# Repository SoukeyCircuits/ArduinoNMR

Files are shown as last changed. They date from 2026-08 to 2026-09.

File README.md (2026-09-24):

August 2026 Update and Explainer:

IMPORTANT DISCLAIMER: The repository here is only the spectrometer for an NMR. You will need to purchase a sufficiently homogeneous magnet and a power amplifier to acquire any kind of measurement. A power amplifier can be purchased from aliexpress for under $100 but your quality and safety will vary significantly. If you are looking for a magnet, there are a few open source options that you can build yourself or commercially available ones.

The magnet used for demonstration can be found here: 
https://www.spincore.com/products/Magnets/
I will do a build of this one: 
https://www.hardware-x.com/article/S2468-0672(25)00029-X/fulltext 
I'm unsure if this is of high quality but would be an interesting build:
https://science.slc.edu/mfrey/project/3dprintnmrmandhalas_update2/

To do list: 
	
  -Upload Accessory PCB files
	
  -Add alternative attenuator and LNA (10 MHz minimum frequency but lower price).
	
  -Upload control code
	
  -Upload Arduino NMR pulse code (being edited for release)
	
  -Upload CAD/CAM designs for the housing and end plates
	
  -Add Arduino Giga Display + display software
	
  -Show preliminary results from working device
	
  -Add non JLC BOM (Mouser, Aliexpress, etc)
	
  -Add raspberry pi multiple instrument control software.

  -Fix phase error discovered at OpenSauce 2026.
  
  -Implement digital filtering techniques.
  
The main sections of the Arduino NMR are the RF synthesis, RF input, and the Tayloe detector. 

RF synthesis begins with the SI5351A-B-GM chip connected to an ABM8G-25.000MHZ-4Y-T3, a  25 MHz crystal oscillator. The 20QFN package for the SI5351 was specifically chosen over the 16QFN as it was having issues with the Etherkit SI5351 library and not indexing the clock outputs correctly. The SI5351A-B-GM is still unable to use CLK6 and CLK7 as they are handled differently from CLK0-CLK5. Although it would be possible to control all 8 outputs, the function is sufficient for the design as is. The primary output clocks CLK0-CLK3 are connected to an ADG904BRUZ in an SP4T configuration. The switch allows for indexing either 0°, 90°, 180°, and 270° phase for a single frequency or 0° and a second phase at two separate frequencies. The lowest frequency for a 0°-90° control is 4.76 MHz due to the lower PLL limit of 600 MHz and the upper divider limit of int-127. For 0°-90°-180°, the lower limit is twice that at 9.52 MHz. Finally, for full 0°-90°-180°-270° control, the lower limit is 14.17 MHz.

The output is then fed into a PE4251MLI-Z SPDT switch. Since both single and dual frequency setups have an available channel containing the 0° at the Larmor frequency, when not transmitting, the channel can be used for Homodyne demodulation. Alternatively, one of the clocks can be set to a secondary offset frequency for Heterodyne demodulation. 

When actively transmitting, the output is sent through a PE43650 attenuator for digital control of the RF power output. Although the PE43650 was chosen based on availability and price, it would be advantageous to include the PE43711B-Z as an option in the future. The PE43650 has 0.5 dB step sizes with a maximum attenuation of 15.5 dB, but an improvement with the PE43711B-Z would give 0.25 dB step sizes and a maximum attenuation of 31.5 dB. For these applications, 0.5 dB is sufficient and maximum power can be limited by an external attenuator on the output(s).

fter attenuation, the final stage is either a bridged solder jumper, or another PE4251MLI-Z SPDT switch. This switch is what controls the two TX output options. Each output will need its own external attenuator to limit the maximum power output as well as a filter. The SI5351 only emits a square shaped output and harmonic frequencies must be filtered out for a pure sinusoidal output at the desired frequency. This allows for connecting a single spectrometer to multiple instruments each with their own dedicated TX and RX ports.

After amplification, further accessory parts are available for filtering, conditioning, and pulse breakthrough limitation. All of these accessories fit inside a 50x25x25mm aluminum enclosure available on Aliexpress but require drilling holes for the SMA connectors. The first accessory is the LC filter. This design is able to fit a 7 pole LC filter within the small enclosure for high off frequency rejection for both ≤100W and ≤5W depending on which side is populated. 

Another accompanying accessory is the crossed-diode duplexer to reject low power noise from the amplifier while passing the high powered pulse. By populating the diodes at the top of the design and not populating the lower diodes, this gives a path of 3 pairs of crossed diodes before reaching the center SMA port leading to the magnet. By changing the diodes populated to the bottom half of the board, bridging the top solder jumper, and not including the center SMA header, the same board can be used for crossed diodes to ground. It should be said, never try to combine these two functions as they are for separate uses and it could damage your equipment.

When attempting to capture the NMR signal, always filter before the signal enters the RX ports. Like with the TX ports, the signal can either go into the default solder bridged SMA connector, or be actively switched between the two RX ports. Once the signal has entered the RX portion of the board, there is one additional PE4251MLI-Z SPDT switch to protect the preamplifier from the pulse breakthrough. This switch is normally closed to a 50 Ω terminator but can be GPIO controlled to open after the desired deadtime. When open, the signal passes into a multiple stage low noise amplifier (LNA). The LNA is a dual stage PHA-13HLN+ amplifier with approximately 48-51 dB of gain with a noise figure ≤3. An additional design with budget conscience in mind alternatively uses a dual GALI-S66+ design for $10 instead of $30. This design has a smaller 42 dB gain and has a similar noise figure above 10 MHz but the noise figure skyrockets below 10 MHz. 

After the preamplifier, the design has one of two options for configuration, bridging the triple solder pad to the left, sends the signal directly into the Tayloe detector. Alternatively, bridging the solder to the right and additionally at the end allows for additional filtering after the LNA. If RX1 and RX2 are close in frequency, the filter can be set to cut off just at the frequency of interest. If the desire is for wide band operation from 1-100 MHz, it is advised to still filter the 100+ MHz frequency as both LNAs have additional noise at or above that frequency. The performance of the LNA and accompanying filtering can be measured by disconnecting C43, not powering the 5V line, and connecting to the center SMA connector as the output. It is advised to validate the gain and noise figure of the LNA prior to connecting to the SN74LV4052ADR. 

Once the signal is amplified and filtered, the signal will pass through the C43 DC blocking capacitor and enter a DC offset of 1.66V using a 3.3V voltage splitter. The signal will then enter the SN74LV4052ADR setup in the configuration of a Tayloe detector inspired by the ESP32 designed https://github.com/thaaraak. As a brief overview, by mixing the 0° and 90° signals from the SI5351 into the SN74LV4052ADR A & B pins and our amplified signal into the COM port, we are able to split the IF into their 0°, 90°, 180°, and 270° components. By then connecting the 0° to the positive end and 180° into the negative end of an operational amplifier, the in-phase signal is the resulting output and can be measured. By repeating with the 90° and 270° components, the quadrature signal can also be acquired. 

Finally, the I/Q signal is measured using the Arduino Giga’s built in ADC pins. Since the clock frequency of the Arduino Giga is 480 MHz, the ADC is capable of measuring up to 12.5 Msps for each channel. This uses the https://github.com/Bexin3/STMSpeeduino as a starting point but uses my built in pulse control software to handle the timing. 

## Repository layout

See `CHANGELOG.md` for what changed since June.

- `BOM_09_23_26.csv` — every part for the main board: JLCPCB assembly, hand solder (front and back), and off-board items with links
- `Arduino_NMR_09_23_26/KiCad_Files/Arduino_NMR_5.4.kicad_pro` — main board; open in KiCad 10
- `Arduino_NMR_09_23_26/KiCad_Files/production/1_jlcpcb_assembly.csv` + `1_jlcpcb_assembly_cpl.csv` — the files to upload to JLCPCB
- `Arduino_NMR_09_23_26/Power-USBC/` — USB-C PD power board (9 V in, +8 V / +3.3 V out)
- `Arduino_NMR_09_23_26/Power_Barrel/` — barrel-jack version of the power board
- `Past Boards/` — earlier revisions, kept as they were

Each power board folder has its own README, BOM, schematic PDF and JLCPCB files. Released boards are tagged in git (e.g. `v5.4-production`).

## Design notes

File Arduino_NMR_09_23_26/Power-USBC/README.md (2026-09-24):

# Power-USBC

USB-C PD power board for the Arduino NMR. It negotiates a fixed 9 V from any USB-C PD supply (HUSB238A-BB001), makes the +8 V (LNA) and +3.3 V rails on board, and feeds them to the main board over J2 (1×12) and J4 (2×5 right-angle).

- **Over-voltage interlock:** a TL431A cuts the input if the supply ever delivers more than ~10 V.
- **Indicators:** LED1–LED3 show +9V_SYS, +8V and +3V3.
- **2 layers, 1.6 mm.**

| File | What |
|---|---|
| `BOM_USBC_09_23_26.csv` | every part: JLCPCB assembly, hand solder, and off-board items |
| `USBC_Power_schematic.pdf` | the schematic |
| `KiCad_Files/usbc-power.kicad_pro` | open this in KiCad 10 |
| `KiCad_Files/production/1_jlcpcb_assembly.csv` + `_cpl.csv` | the files to upload to JLCPCB |

## Known issues

- **The R23 failsafe is in the schematic but not on the PCB.** The schematic has R23 and R32 at 6.04k in parallel, so a single failed resistor gives 12 V (caught by the interlock) instead of 28 V. The PCB and BOM still have a single 3.00k R23. Run *Update PCB from Schematic* before the next order.
- **J10 (USB-C receptacle):** JLC doesn't stock the GCT USB4105-GF-A-120 (48 V). Either hand solder it or switch to the HRO TYPE-C-31-M-12 (C165948), which is rated 20 V only.
- **IC25 (BD33GA5WEFJ-E2)** is out of stock at JLC. Hand solder it.
- **D20 (SMAJ24A)** clamps at 38.9 V, which is above U20's 33 V absolute maximum. Acceptable for a test board.

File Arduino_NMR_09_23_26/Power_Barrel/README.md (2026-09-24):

# Power_Barrel

Barrel-jack version of the Power-USBC board. The PD negotiation and interlock are gone. It takes a DC input on J1 (PJ-058B), makes the +8 V (BD80GC0VEFJ-ME2) and +3.3 V (BD33GA5WEFJ-E2) rails, and feeds the main board over the same J2 (1×12) and J4 (2×5 right-angle) connectors.

| File | What |
|---|---|
| `BOM_Barrel_09_23_26.csv` | every part: JLCPCB assembly, hand solder, and off-board items |
| `Barrel_Power_schematic.pdf` | the schematic |
| `KiCad_Files/Barrel_Power.kicad_pro` | open this in KiCad 10 |
| `KiCad_Files/production/1_jlcpcb_assembly.csv` + `_cpl.csv` | the files to upload to JLCPCB |

## Status

**Not yet built or ordered.** The input voltage range hasn't been confirmed against the regulators; check the BD80 dropout before choosing a supply. IC25 is out of stock at JLC, so hand solder it.

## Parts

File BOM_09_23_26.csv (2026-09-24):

Assembly | Value | Designator | Footprint | Qty | Category | Part Number | Supplier | Link | Notes
JLCPCB assembly (front) | 0603CS-5N1XJLW | L1, L3 | 0603 | 2 | SMD |  | JLCPCB |  | Pick from JLC suggested parts
JLCPCB assembly (front) | 1 nF | C40, C64 | 0402 | 2 | SMD | 0402B102K500NT | JLCPCB
JLCPCB assembly (front) | 1 nF | C2, C4, C5, C6, C15, C16 | 0805 | 6 | SMD |  | JLCPCB |  | Pick from JLC suggested parts
JLCPCB assembly (front) | 1 uF | C48 | 0805 | 1 | SMD |  | JLCPCB |  | Pick from JLC suggested parts
JLCPCB assembly (front) | 1.5 k | R16, R17 | 0402 | 2 | SMD | 0402WGF1501TCE | JLCPCB
JLCPCB assembly (front) | 1.5 pF | C20, C46 | 0402 | 2 | SMD | 0402CG1R5C500NT | JLCPCB
JLCPCB assembly (front) | 10 uF | C41, C65 | 0805 | 2 | SMD | GRM21BR61H106KE43L | JLCPCB
JLCPCB assembly (front) | 100 nF | C1, C3, C14, C34, C43 | 0805 | 5 | SMD |  | JLCPCB |  | Pick from JLC suggested parts
JLCPCB assembly (front) | 100 nF | C31, C61 | 0402 | 2 | SMD | CL05B104KO5NNNC | JLCPCB
JLCPCB assembly (front) | 100 pF | C8, C9, C27, C28 | 0805 | 4 | SMD |  | JLCPCB |  | Pick from JLC suggested parts
JLCPCB assembly (front) | 100Ω | R1, R6, R7, R13, R14, R15 | 0805 | 6 | SMD |  | JLCPCB |  | Pick from JLC suggested parts
JLCPCB assembly (front) | 10kΩ | R3, R4, R9, R10 | 0805 | 4 | SMD |  | JLCPCB |  | Pick from JLC suggested parts
JLCPCB assembly (front) | 1kΩ | R5, R8 | 0805 | 2 | SMD | 0805W8F1001T5E | JLCPCB
JLCPCB assembly (front) | 2.2 uF | C30, C45, C60, C66 | 0603 | 4 | SMD |  | JLCPCB |  | Pick from JLC suggested parts
JLCPCB assembly (front) | 50Ω | R18 | 0805 | 1 | SMD |  | JLCPCB |  | Pick from JLC suggested parts
JLCPCB assembly (front) | ABM8G-25.000MHZ-B4Y-T | Y1 | Crystal_SMD_SeikoEpson_FA238-4Pin_3.2x2.5mm_HandSoldering | 1 | SMD |  | JLCPCB |  | Pick from JLC suggested parts
JLCPCB assembly (front) | ADG904BRUZ-REEL7 | IC3 | ADG904BRUZ | 1 | SMD |  | JLCPCB |  | Pick from JLC suggested parts
JLCPCB assembly (front) | LM4562MAX/NOPB | U4 | SOIC-8-1EP_3.9x4.9mm_P1.27mm_EP2.29x3mm_nobottomgnd | 1 | SMD |  | JLCPCB |  | Pick from JLC suggested parts
JLCPCB assembly (front) | LQH32DZ150K53L | L2, L15 | 1210 | 2 | SMD |  | JLCPCB |  | Pick from JLC suggested parts
JLCPCB assembly (front) | PE4251MLI-Z | IC4, IC8, IC10, IC11 | SOP65P490X106-9N | 4 | SMD |  | JLCPCB |  | Pick from JLC suggested parts
JLCPCB assembly (front) | PE43711B-Z | AT2 | PE43711B-Z | 1 | SMD |  | JLCPCB |  | Pick from JLC suggested parts
JLCPCB assembly (front) | PHA-13HLN+ | IC13, IC14 | PHA13HLN | 2 | SMD |  | JLCPCB |  | Pick from JLC suggested parts
JLCPCB assembly (front) | SN74LV1T04DBVR | IC1, IC2, IC12 | SOT95P280X145-5N | 3 | SMD |  | JLCPCB |  | Pick from JLC suggested parts
JLCPCB assembly (front) | SN74LV4052ADR | U1 | SOIC-16_3.9x9.9mm_P1.27mm | 1 | SMD |  | JLCPCB |  | Pick from JLC suggested parts
JLCPCB assembly (front) | Si5351A-B-GM | U2 | QFN-20-1EP_4x4mm_P0.5mm_EP2.7x2.7mm | 1 | SMD |  | JLCPCB |  | Pick from JLC suggested parts
JLCPCB assembly (front) | TLV74125PDBVR | IC5 | SOT95P280X145-5N | 1 | SMD |  | JLCPCB |  | Pick from JLC suggested parts
Hand solder (back) | 100 uF | C47 | C_Radial_D5.0mm_H5.0mm_P2.00mm | 1 | Bulk cap (THT) |  |  |  | Through-hole electrolytic on the BACK side - hand solder.
Hand solder (back) | Conn_01x02 | J4, J10, J12 | PinHeader_1x02_P2.54mm_Vertical | 3 | Connector (THT) |  |  |  | Through-hole connector on the BACK side - hand solder.
Hand solder (back) | Digital | J5 | PinHeader_2x18_P2.54mm_Vertical | 1 | Connector (THT) |  |  |  | Through-hole connector on the BACK side - hand solder.
Hand solder (back) | 100 nF | C10, C17, C18, C19, C24 | 0805 | 5 | Decoupling |  |  |  | Back-side hand soldering.
Hand solder (back) | 100 pF | C29, C33, C39 | 0805 | 3 | Decoupling |  |  |  | Back-side hand soldering.
Hand solder (front) | Conn_01x05 | J7 | PinHeader_1x05_P2.54mm_Vertical | 1 | Connector (THT) |  |  |  | Through-hole connector - hand solder.
Hand solder (front) | Conn_01x12 | J2 | PinHeader_1x12_P2.54mm_Vertical | 1 | Connector (THT) |  |  |  | Through-hole connector - hand solder.
Hand solder (front) | RX1 | J11 | SMA_Amphenol_901-144_Vertical | 1 | Connector (THT) |  |  |  | Through-hole connector - hand solder.
Hand solder (front) | RX2 | J40 | SMA_Amphenol_901-144_Vertical | 1 | Connector (THT) |  |  |  | Through-hole connector - hand solder.
Hand solder (front) | Ringdown | J6, J41 | SMA_Amphenol_901-144_Vertical | 2 | Connector (THT) |  |  |  | Through-hole connector - hand solder.
Hand solder (front) | TX1 | J8 | SMA_Amphenol_901-144_Vertical | 1 | Connector (THT) |  |  |  | Through-hole connector - hand solder.
Hand solder (front) | 180 pF | C141, C142, C143, C144, C145, C146, C150, C151, C152, C153 | 0805 | 10 | Filter capacitor |  |  |  | Filter capacitor - choose value to suit the required filtering. If filtering is done off-board, DNP. Do NOT bridge with 0 ohm jumper resistors.
Hand solder (front) | 47 pF | C62, C63, C67, C68, C69, C147, C148, C149, C154, C155 | 0805 | 10 | Filter capacitor |  |  |  | Filter capacitor - choose value to suit the required filtering. If filtering is done off-board, DNP. Do NOT bridge with 0 ohm jumper resistors.
Hand solder (front) | 330 nH | L13, L14, L16, L17, L18, L47, L48, L49, L52, L53 | 0805 | 10 | Filter inductor |  |  |  | Filter inductor - choose value to suit the required filtering. If filtering is done after the board, replace with a 0 ohm jumper resistor (0805).
Hand solder (front) | 470 nH | L44, L45, L46, L50, L51 | 0805 | 5 | Filter inductor |  |  |  | Filter inductor - choose value to suit the required filtering. If filtering is done after the board, replace with a 0 ohm jumper resistor (0805).
Hand solder (front) | D | D1 | D_SMA_Handsoldering | 1 | Protection diode |  |  |  | Protection diode - VALUE TBD, confirm before ordering. Hand solder.
Hand solder (front) | RFShield_OnePiece | J32 | RF Shield_2 | 1 | RF shield |  | Mouser | https://www.mouser.com/en/ProductDetail/388-MS329-10S | RF shield - hand solder after all other assembly.
Hand solder (front) | RFShield_OnePiece | J17 | RF Shield_3 | 1 | RF shield |  | Mouser | https://www.mouser.com/en/ProductDetail/388-MS329-10S | RF shield - hand solder after all other assembly.
Hand solder (front) | RFShield_OnePiece | J16 | RF Shield_1 | 1 | RF shield |  | Mouser | https://www.mouser.com/en/ProductDetail/388-MS329-10S | RF shield - hand solder after all other assembly.
Hand solder (front) | Jumper_2_Open | JP2, JP5, JP8 | SolderJumper-2_P1.3mm_Open_Pad1.0x1.5mm | 3 | Solder jumper |  |  |  | PCB solder bridge - nothing to purchase; bridge by hand as required.
Hand solder (front) | SolderJumper_3_Open | JP4 | SolderJumper-3_P1.3mm_Open_Pad1.0x1.5mm | 1 | Solder jumper |  |  |  | PCB solder bridge - nothing to purchase; bridge by hand as required.
External (not on PCB) | Aluminium enclosure |  |  | 1 |  |  | Amazon | https://www.amazon.com/dp/B012SYN4OO
External (not on PCB) | M3 standoffs |  |  | 1 | Assorted M3 standoff kit |  | AliExpress | https://www.aliexpress.us/item/3256808109877301.html
External (not on PCB) | Arduino Giga R1 WiFi |  |  | 1 | ABX00063 - board only |  | Amazon | https://www.amazon.com/dp/B0BTTRZ9TB | Alternative with display: https://www.amazon.com/dp/B0G1L5C7MG
External (not on PCB) | USB-C power supply |  |  | 1 |  |  | Amazon | https://www.amazon.com/dp/B0CYZHY7BX
External (not on PCB) | USB-C cable |  |  | 1 |  |  | Amazon | https://www.amazon.com/dp/B0CJY9PRNY | Alternative: https://www.amazon.com/dp/B0BLYXSTSQ
External (not on PCB) | SMA connectors |  |  | 1 | SMA-KWE 17 mm, 50 pcs |  | AliExpress | https://www.aliexpress.us/item/3256808128195000.html | Mates with the board SMA footprints
External (not on PCB) | 2.54 mm header pins |  |  | 1 | 40P strip, cut to size |  | AliExpress | https://www.aliexpress.us/item/3256806907643797.html
External (not on PCB) | Heat sink - LNA |  |  | 0 |  |  |  |  | TBD
External (not on PCB) | Enclosure fan |  |  | 0 |  |  |  |  | TBD
External (not on PCB) | 0 ohm jumper resistors 0805 |  |  | 0 | Only if filtering is done off-board - see filter inductor note

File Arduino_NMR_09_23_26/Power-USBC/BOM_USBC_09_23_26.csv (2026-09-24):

Assembly | Value | Designator | Footprint | Qty | Category | Part Number | Supplier | Link | Notes
JLCPCB assembly (front) | 10 nF | C12, C25, C26, C28 | 0805 | 4 | SMD |  | JLCPCB |  | Pick from JLC suggested parts
JLCPCB assembly (front) | 1uF/50V | C20, C21 | 0603 | 2 | SMD |  | JLCPCB |  | Pick from JLC suggested parts
JLCPCB assembly (front) | 22uF/25V | C22, C23 | 1206 | 2 | SMD |  | JLCPCB |  | Pick from JLC suggested parts
JLCPCB assembly (front) | 100nF/50V | C24 | 0402 | 1 | SMD |  | JLCPCB |  | Pick from JLC suggested parts
JLCPCB assembly (front) | 4.7nF | C27 | 0402 | 1 | SMD |  | JLCPCB |  | Pick from JLC suggested parts
JLCPCB assembly (front) | 10nF/50V | C30 | 0402 | 1 | SMD |  | JLCPCB |  | Pick from JLC suggested parts
JLCPCB assembly (front) | SMAJ24A | D20 | SMASeries_LTF | 1 | SMD | C132947 | JLCPCB
JLCPCB assembly (front) | SMAJ11A | D21 | DIOM5127X229N | 1 | SMD |  | JLCPCB |  | Pick from JLC suggested parts
JLCPCB assembly (front) | BZX84C10 | D22 | P200_SOT-23 | 1 | SMD | C118575 | JLCPCB
JLCPCB assembly (front) | BD80GC0VEFJ-ME2 | IC7 | SOIC127P600X100-9N | 1 | SMD |  | JLCPCB |  | Pick from JLC suggested parts
JLCPCB assembly (front) | USB4105-GF-A-120 | J10 | USB_C_Receptacle_GCT_USB4105-xx-A_16P_TopMnt_Horizontal | 1 | SMD |  | JLCPCB |  | DECISION PENDING: GCT USB4105-GF-A-120 (48 V, 1.20 mm stakes for a 1.6 mm board) is not stocked by JLC - hand solder it, or switch the board to HRO TYPE-C-31-M-12 (C165948) which JLC stocks but is rated 20 V only.
JLCPCB assembly (front) | RED | LED1, LED2, LED3 | 0805 | 3 | SMD | C2295 | JLCPCB
JLCPCB assembly (front) | DMP3013SFV-7 | Q20 | DMP3036SFV7 | 1 | SMD | C264098 | JLCPCB
JLCPCB assembly (front) | BSS84 | Q22 | SOT95P240X120-3N | 1 | SMD | C114481 | JLCPCB
JLCPCB assembly (front) | 10R | R20 | 0402 | 1 | SMD |  | JLCPCB |  | Pick from JLC suggested parts
JLCPCB assembly (front) | 5.1k | R21 | 0402 | 1 | SMD |  | JLCPCB |  | Pick from JLC suggested parts
JLCPCB assembly (front) | 100k | R22 | 0402 | 1 | SMD |  | JLCPCB |  | Pick from JLC suggested parts
JLCPCB assembly (front) | 3.00k 1% | R23 | 0402 | 1 | SMD |  | JLCPCB |  | Pick from JLC suggested parts
JLCPCB assembly (front) | 2.26k 1% | R24 | 0402 | 1 | SMD |  | JLCPCB |  | Pick from JLC suggested parts
JLCPCB assembly (front) | 1M | R25, R26, R27 | 0402 | 3 | SMD |  | JLCPCB |  | Pick from JLC suggested parts
JLCPCB assembly (front) | 2.2k | R29, R36 | 0402 | 2 | SMD |  | JLCPCB |  | Pick from JLC suggested parts
JLCPCB assembly (front) | 30.1k 1% | R30 | 0402 | 1 | SMD |  | JLCPCB |  | Pick from JLC suggested parts
JLCPCB assembly (front) | 10.0k 1% | R31 | 0402 | 1 | SMD |  | JLCPCB |  | Pick from JLC suggested parts
JLCPCB assembly (front) | 6.8k | R34 | 0402 | 1 | SMD |  | JLCPCB |  | Pick from JLC suggested parts
JLCPCB assembly (front) | 1k | R35 | 0402 | 1 | SMD |  | JLCPCB |  | Pick from JLC suggested parts
JLCPCB assembly (front) | 390 | R37 | 0402 | 1 | SMD |  | JLCPCB |  | Pick from JLC suggested parts
JLCPCB assembly (front) | HUSB238A-BB001-QN16R | U20 | QFN-16-1EP_3x3mm_P0.5mm_EP1.7x1.7mm_ThermalVias | 1 | SMD | C24833806 | JLCPCB
JLCPCB assembly (front) | TL431A | U21 | SOT-23 | 1 | SMD |  | JLCPCB |  | Pick from JLC suggested parts
Hand solder (front) | BD33GA5WEFJ-E2 | IC25 | SOIC127P600X100-9N | 1 | ROHM BD33GA5WEFJ-E2 - 3.3 V LDO, HTSOP-J8 |  |  |  | OUT OF STOCK at JLCPCB (2 shortfall) - excluded from machine assembly. Hand solder after the board returns. Order separately.
Hand solder (front) | Conn_01x12 | J2 | PinHeader_1x12_P2.54mm_Vertical | 1 | 2.54 mm pin header, 1x12 vertical |  | AliExpress | https://www.aliexpress.us/item/3256806907643797.html | Cut to length from a 40P single-row 2.54 mm strip.
Hand solder (front) | Conn_02x05_Odd_Even | J4 | PinHeader_2x05_P2.54mm_Horizontal | 1 | 2.54 mm pin header, 2x5 right-angle |  | AliExpress | https://www.aliexpress.us/item/3256806736246215.html | Right-angle dual-row header - mates coplanar with the RF board.
External (not on PCB) | USB-C cable |  |  | 1 | 100 W, 1 m |  | Amazon | https://www.amazon.com/dp/B0CJY9PRNY
External (not on PCB) | USB-C power supply |  |  | 1 |  |  | Amazon | https://www.amazon.com/dp/B0CYZHY7BX
External (not on PCB) | 2.54 mm header sockets |  |  | 1 | Mating half for J2 / J4 on the RF board
External (not on PCB) | M3 standoffs |  |  | 1 | Register the two boards so the connectors cannot slide a column |  | AliExpress | https://www.aliexpress.us/item/3256808109877301.html

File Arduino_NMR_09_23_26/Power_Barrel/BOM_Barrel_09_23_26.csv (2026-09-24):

Assembly | Value | Designator | Footprint | Qty | Category | Part Number | Supplier | Link | Notes
JLCPCB assembly (front) | 10 nF | C12, C25, C26, C28 | 0805 | 4 | SMD |  | JLCPCB |  | Pick from JLC suggested parts
JLCPCB assembly (front) | BD80GC0VEFJ-ME2 | IC7 | SOIC127P600X100-9N | 1 | SMD |  | JLCPCB |  | Pick from JLC suggested parts
Hand solder (front) | PJ-058B | J1 | PJ058B | 1 | Barrel jack (THT) | PJ-058B |  |  | Through-hole - hand solder.
Hand solder (front) | BD33GA5WEFJ-E2 | IC25 | SOIC127P600X100-9N | 1 | 3.3 V LDO |  |  |  | Out of stock at JLCPCB - hand solder, order separately.
Hand solder (front) | Conn_01x12 | J2 | PinHeader_1x12_P2.54mm_Vertical | 1 | Connector (THT) |  | AliExpress | https://www.aliexpress.us/item/3256806907643797.html | Cut to length from a 40P single-row 2.54 mm strip.
Hand solder (front) | Conn_02x05_Odd_Even | J4 | PinHeader_2x05_P2.54mm_Horizontal | 1 | Connector (THT) |  | AliExpress | https://www.aliexpress.us/item/3256806736246215.html | Right-angle dual-row header - mates coplanar with the RF board.
External (not on PCB) | 2.54 mm header sockets |  |  | 1 | Mating half for J2 / J4 on the RF board
External (not on PCB) | M3 standoffs |  |  | 1 | Register the two boards so the connectors cannot slide a column |  | AliExpress | https://www.aliexpress.us/item/3256808109877301.html
External (not on PCB) | Barrel-jack power supply |  |  | 1 | 9-12 V DC, 2.1 mm centre-positive - confirm against PJ-058B |  |  |  | TBD

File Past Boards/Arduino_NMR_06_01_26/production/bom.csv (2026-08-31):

Designator | Footprint | Quantity | Value | LCSC Part #
_4, _3, _2, |  | 4
AT2 | PE43711B-Z | 1 | PE43711B-Z
C1, C14, C3 | 0805 | 3 | 100 nF
C11, C12, C21, C22, C23, C26 | 0805 | 6 | 10 nF
C15, C16, C2, C4, C5, C6 | 0805 | 6 | 1 nF
C20, C46 | 0402 | 2 | 1.5 pF
C27, C28, C29, C32, C33, C39, C42, C8, C9 | 0805 | 9 | 100 pF
C30, C45, C60, C66 | 0603 | 4 | 2.2 uF
C31, C61 | 0402 | 2 | 100 nF
C40, C64 | 0402 | 2 | 1 nF
C41, C65 | 0805 | 2 | 10 uF
C43 | 0805 | 1 | 1 pF
C47 | C_Radial_D5.0mm_H5.0mm_P2.00mm | 1 | 100 uF
IC1, IC12, IC2 | SOT95P280X145-5N | 3 | SN74LV1T04DBVR
IC10, IC11, IC4, IC8, IC9 | SOP65P490X106-9N | 5 | PE4251MLI-Z
IC13, IC14 | PHA13HLN | 2 | PHA-13HLN+
IC25 | SOIC127P600X100-9N | 1 | BD33GA5WEFJ-E2
IC3 | ADG904BRUZ | 1 | ADG904BRUZ-REEL7
IC6 | SOIC127P600X100-9N | 1 | BD50GC0VEFJ-ME2
IC7 | SOIC127P600X100-9N | 1 | BD80GC0VEFJ-ME2
L1, L3 | 0603 | 2 | 0603CS-5N1XJLW
L15, L2 | 1210 | 2 | LQH32DZ150K53L
R1, R13, R14, R15, R6, R7 | 0805 | 6 | 100Ω
R10, R3, R4, R9 | 0805 | 4 | 10kΩ
R16, R17 | 0402 | 2 | 1.5 k
R5, R8 | 0805 | 2 | 1kΩ
U1 | SOIC-16_3.9x9.9mm_P1.27mm | 1 | SN74LV4052ADR
U2 | QFN-20-1EP_4x4mm_P0.5mm_EP2.7x2.7mm | 1 | Si5351A-B-GM
U4 | SOIC-8-1EP_3.9x4.9mm_P1.27mm_EP2.29x3mm_nobottomgnd | 1 | LM4562MAX/NOPB
Y1 | Crystal_SMD_SeikoEpson_FA238-4Pin_3.2x2.5mm_HandSoldering | 1 | ABM8G-25.000MHZ-B4Y-T

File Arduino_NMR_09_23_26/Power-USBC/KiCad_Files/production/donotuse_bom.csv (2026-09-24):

Designator | Footprint | Quantity | Value | LCSC Part #
C12, C25, C26, C28 | 0805 | 4 | 10 nF
C20, C21 | 0603 | 2 | 1uF/50V
C22, C23 | 1206 | 2 | 22uF/25V
C24 | 0402 | 1 | 100nF/50V
C27 | 0402 | 1 | 4.7nF
C30 | 0402 | 1 | 10nF/50V
D20 | SMASeries_LTF | 1 | SMAJ24A | C132947
D21 | DIOM5127X229N | 1 | SMAJ11A
D22 | P200_SOT-23 | 1 | BZX84C10 | C118575
IC25 | SOIC127P600X100-9N | 1 | BD33GA5WEFJ-E2
IC7 | SOIC127P600X100-9N | 1 | BD80GC0VEFJ-ME2
J10 | USB_C_Receptacle_GCT_USB4105-xx-A_16P_TopMnt_Horizontal | 1 | USB4105-GF-A-120
J2 | PinHeader_1x12_P2.54mm_Vertical | 1 | Conn_01x12
J4 | PinHeader_2x05_P2.54mm_Horizontal | 1 | Conn_02x05_Odd_Even
LED1, LED2, LED3 | 0805 | 3 | RED
Q20 | DMP3036SFV7 | 1 | DMP3013SFV-7 | C264098
Q22 | SOT95P240X120-3N | 1 | BSS84 | C427395
R20 | 0402 | 1 | 10R
R21 | 0402 | 1 | 5.1k
R22 | 0402 | 1 | 100k
R23 | 0402 | 1 | 3.00k 1%
R24 | 0402 | 1 | 2.26k 1%
R25, R26, R27 | 0402 | 3 | 1M
R29, R36 | 0402 | 2 | 2.2k
R30 | 0402 | 1 | 30.1k 1%
R31 | 0402 | 1 | 10.0k 1%
R34 | 0402 | 1 | 6.8k
R35 | 0402 | 1 | 1k
R37 | 0402 | 1 | 390
U20 | QFN-16-1EP_3x3mm_P0.5mm_EP1.7x1.7mm_ThermalVias | 1 | HUSB238A-BB001-QN16R | C24833806
U21 | SOT-23 | 1 | TL431A

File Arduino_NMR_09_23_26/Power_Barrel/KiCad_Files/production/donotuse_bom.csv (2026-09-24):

Designator | Footprint | Quantity | Value | LCSC Part #
C12, C25, C26, C28 | 0805 | 4 | 10 nF
IC25 | SOIC127P600X100-9N | 1 | BD33GA5WEFJ-E2
IC7 | SOIC127P600X100-9N | 1 | BD80GC0VEFJ-ME2
J2 | PinHeader_1x12_P2.54mm_Vertical | 1 | Conn_01x12
J4 | PinHeader_2x05_P2.54mm_Horizontal | 1 | Conn_02x05_Odd_Even

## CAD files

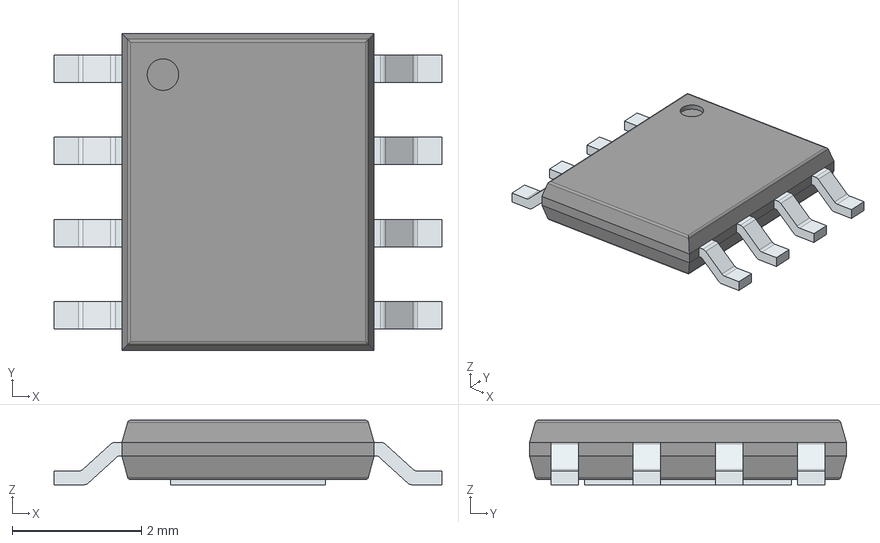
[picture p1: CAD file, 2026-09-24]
Arduino_NMR_09_23_26/Power-USBC/KiCad_Files/3dmodels/HTSOP-J8.stp
6.00 x 4.90 x 1.00 mm
PinsArrayLR
ThermalPad

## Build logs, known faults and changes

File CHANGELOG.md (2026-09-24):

# Changelog

All notable changes to the Arduino Giga NMR spectrometer board.

Revisions are dated by the folder they were developed in. Part counts are
footprints carrying a reference designator, excluding mounting holes.

---

## [5.4] — 2026-09-22 — *sent to production*

The power supply left the board. Everything that generated a rail now lives on
a separate 2-layer USB-C PD board, and this board receives its rails over a
connector instead.

**126 parts** (was 108) · 4 layers · 120 × 79 mm

### Removed — on-board power generation

| Ref | Part | Was |
|---|---|---|
| J1 | `PJ-058B` | barrel jack input |
| IC6 | `BD50GC0VEFJ-ME2` | +5 V regulator |
| IC7 | `BD80GC0VEFJ-ME2` | +8 V regulator (LNA rail) |
| IC25 | `BD33GA5WEFJ-E2` | +3.3 V regulator |
| C11, C12, C21, C22, C23, C26, C32, C42 | 10 nF etc. | regulator decoupling |
| IC9 | `PE4251MLI-Z` | one RF switch |

### Added — inter-board connectors

- **J2** — 1×12 header, carrying +8V, +3V3, VIN and the control/TTL lines
- **J7** — 1×05 header
- **R18** — 50 Ω

### Added — RF filter bank

Sixteen capacitors (C63, C67–C69, C142–C155) and ten inductors (L14, L16–L18,
L45–L46, L48–L53) forming an LC ladder in the receive path. Values are chosen
per build; if filtering is done off-board the inductors become 0 Ω jumpers and
the capacitors are left unpopulated.

### Changed

- **C43** 1 pF → 100 nF

### Repository and tooling

- All footprints consolidated into `Arduino_NMR.pretty` (54), so a fresh clone
  resolves without the author's personal library table
- Recovered `L_0805_2012Metric_Pad1.15x1.40mm_HandSolder`, which KiCad 10
  dropped from its stock library, from the board itself
- 261 footprint references repointed; dead `Library` entry removed from
  `fp-lib-table`
- Repository reorganised: this board's KiCad project in
  `Arduino_NMR_09_23_26/KiCad_Files/`, the power boards beside it, and the June
  board in `Past Boards/`
- One combined BOM, `BOM_09_23_26.csv`, covering JLCPCB assembly, back- and
  front-side hand solder, and off-board parts
- JLCPCB upload files are `Arduino_NMR_09_23_26/KiCad_Files/production/1_jlcpcb_assembly.csv` and
  `1_jlcpcb_assembly_cpl.csv`; the raw Fabrication Toolkit output is kept as
  `donotuse_bom.csv` / `donotuse_positions.csv`
- Sheets not in the hierarchy removed

---

## [5.2] — 2026-06 — *baseline*

**108 parts** · 4 layers. Self-powered from a barrel jack, with on-board +5 V,
+8 V and +3.3 V regulators and six RF switches.

---

## Companion boards

Developed alongside 5.4, in `Arduino_NMR_09_23_26/`:

- **Power-USBC 1.0** — *sent to production 2026-09-22.* 9 V USB-C PD sink
  (HUSB238A-BB001) with the +8 V and +3.3 V regulators moved across from this
  board, a TL431A hardware over-voltage interlock, and three rail indicator LEDs
- **Power_Barrel** — *not yet ordered.* Barrel-jack version of the same board,
  with no PD negotiation or interlock

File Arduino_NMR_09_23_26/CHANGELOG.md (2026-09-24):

# Changelog

All notable changes to the Arduino Giga NMR spectrometer board.

Revisions are dated by the folder they were developed in. Part counts are
footprints carrying a reference designator, excluding mounting holes.

---

## [5.4] — 2026-09-22 — *sent to production*

The power supply left the board. Everything that generated a rail now lives on
a separate 2-layer USB-C PD board, and this board receives its rails over a
connector instead.

**126 parts** (was 108) · 4 layers · 120 × 79 mm

### Removed — on-board power generation

| Ref | Part | Was |
|---|---|---|
| J1 | `PJ-058B` | barrel jack input |
| IC6 | `BD50GC0VEFJ-ME2` | +5 V regulator |
| IC7 | `BD80GC0VEFJ-ME2` | +8 V regulator (LNA rail) |
| IC25 | `BD33GA5WEFJ-E2` | +3.3 V regulator |
| C11, C12, C21, C22, C23, C26, C32, C42 | 10 nF etc. | regulator decoupling |
| IC9 | `PE4251MLI-Z` | one RF switch |

### Added — inter-board connectors

- **J2** — 1×12 header, carrying +8V, +3V3, VIN and the control/TTL lines
- **J7** — 1×05 header
- **R18** — 50 Ω

### Added — RF filter bank

Sixteen capacitors (C63, C67–C69, C142–C155) and ten inductors (L14, L16–L18,
L45–L46, L48–L53) forming an LC ladder in the receive path. Values are chosen
per build; if filtering is done off-board the inductors become 0 Ω jumpers and
the capacitors are left unpopulated.

### Changed

- **C43** 1 pF → 100 nF

### Repository and tooling

- All footprints consolidated into `Arduino_NMR.pretty` (54), so a fresh clone
  resolves without the author's personal library table
- Recovered `L_0805_2012Metric_Pad1.15x1.40mm_HandSolder`, which KiCad 10
  dropped from its stock library, from the board itself
- 261 footprint references repointed; dead `Library` entry removed from
  `fp-lib-table`
- Repository reorganised: this board in `Arduino_NMR_09_23_26/` with the
  KiCad project in `KiCad_Files/`, and the June board in `Past Boards/`
- One combined BOM, `BOM_09_23_26.csv`, covering JLCPCB assembly, back- and
  front-side hand solder, and off-board parts
- JLCPCB upload files are `KiCad_Files/production/1_jlcpcb_assembly.csv` and
  `1_jlcpcb_assembly_cpl.csv`; the raw Fabrication Toolkit output is kept as
  `donotuse_bom.csv` / `donotuse_positions.csv`
- Sheets not in the hierarchy removed

---

## [5.2] — 2026-06 — *baseline*

**108 parts** · 4 layers. Self-powered from a barrel jack, with on-board +5 V,
+8 V and +3.3 V regulators and six RF switches.

---

## Companion boards

Developed alongside 5.4 and sent to production the same day, in its own
repository:

- **usbc-power 1.0** — 9 V USB-C PD sink (HUSB238A-BB001) with the +8 V and
  +3.3 V regulators moved across from this board, plus a TL431A hardware
  over-voltage interlock

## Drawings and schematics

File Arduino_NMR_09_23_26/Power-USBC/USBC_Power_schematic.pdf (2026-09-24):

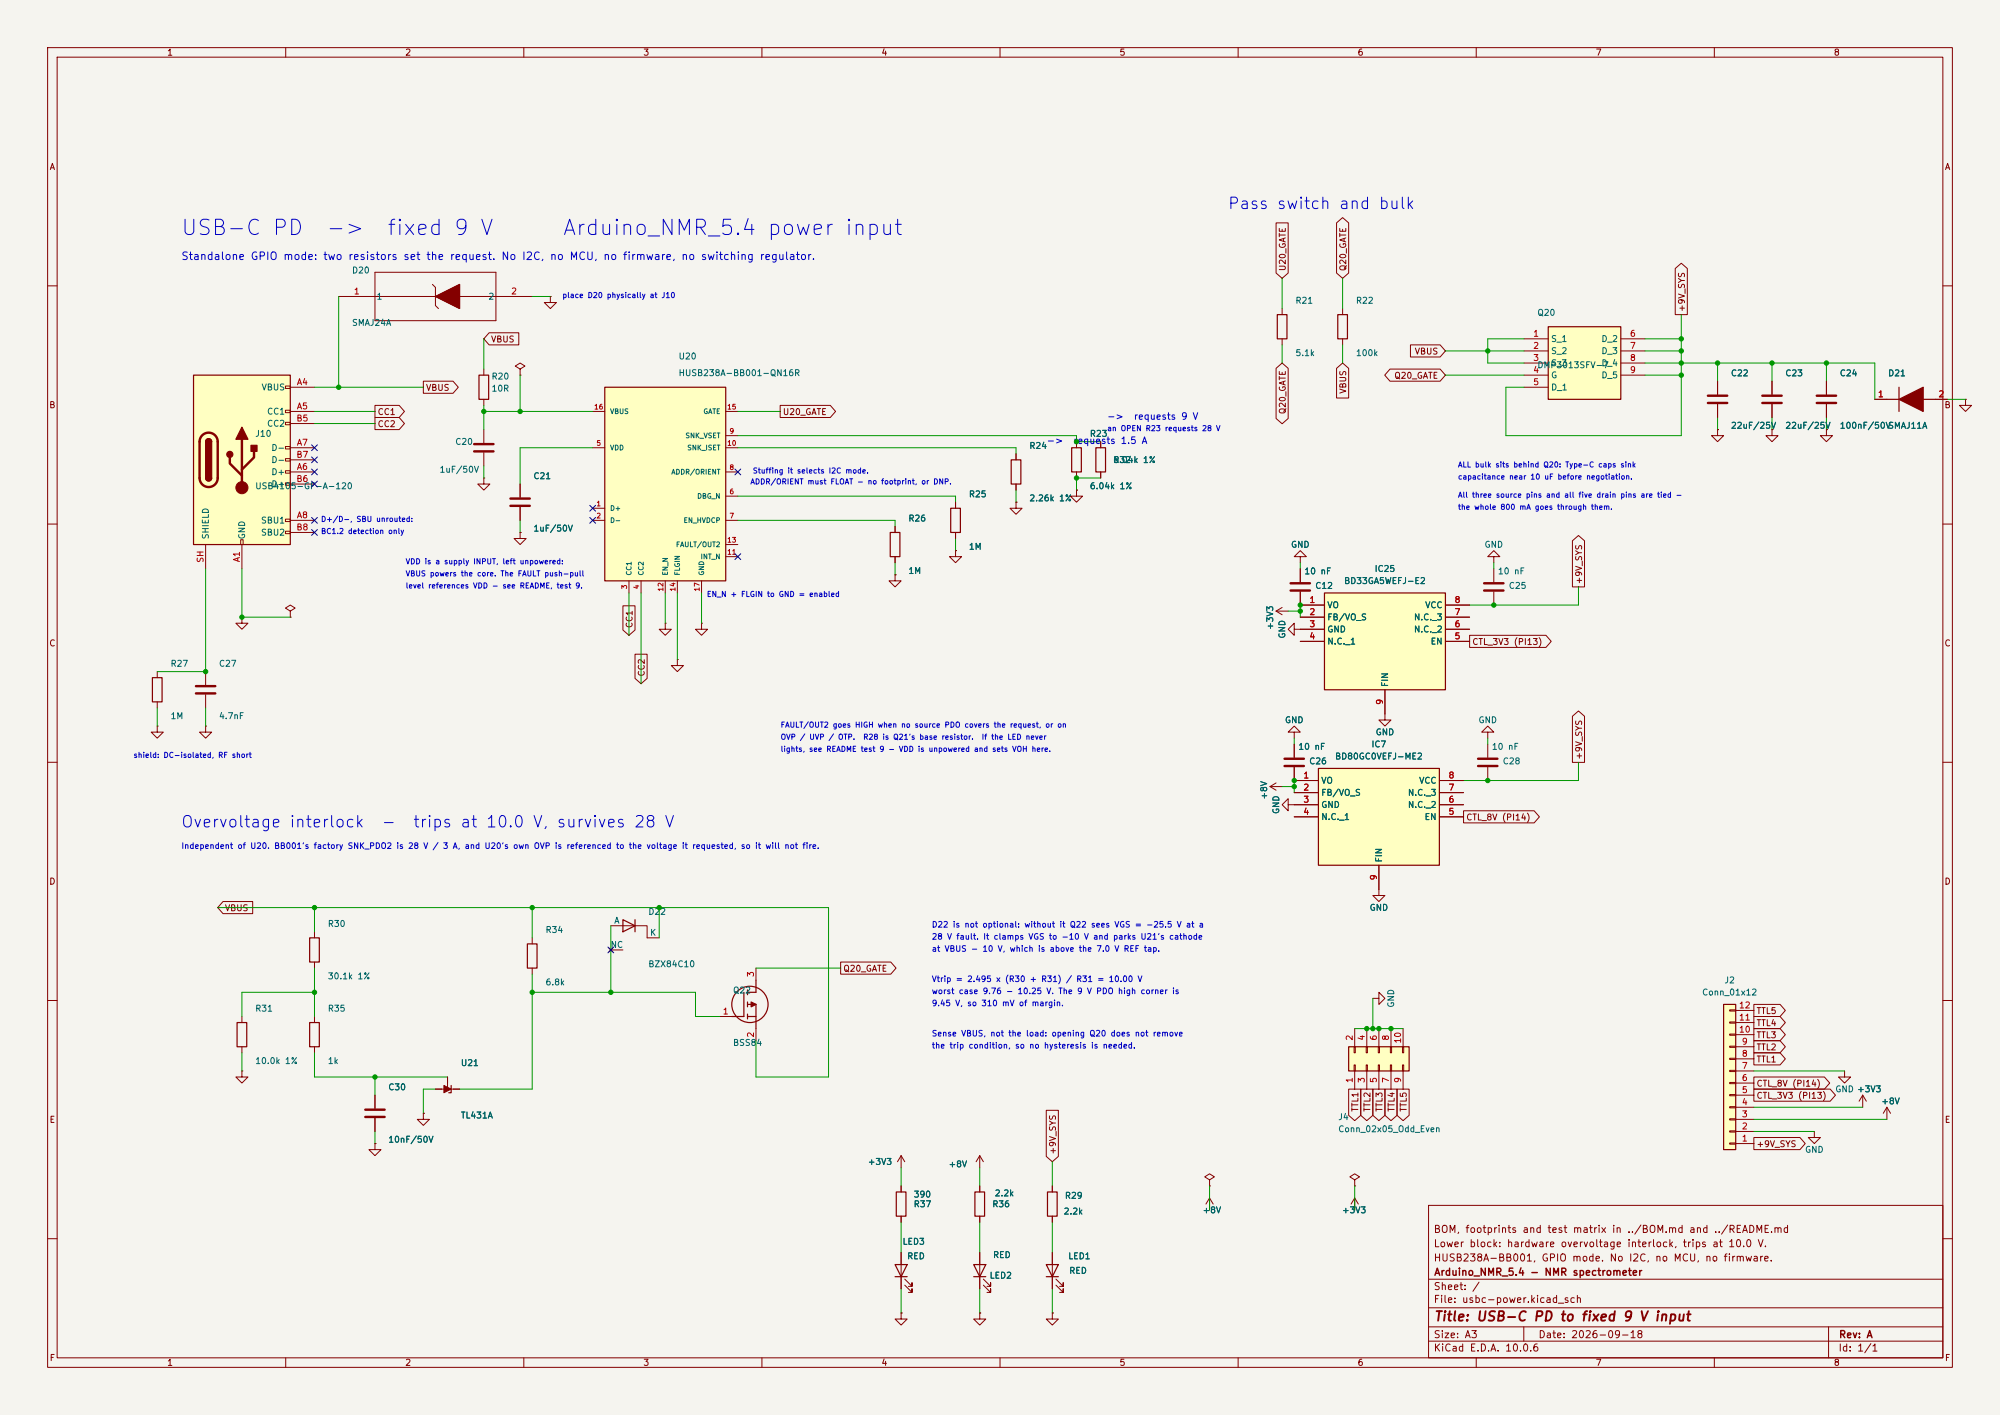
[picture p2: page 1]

capacitance near 10 uF before negotiation. the whole 800 mA goes through them. Pass switch and bulk

ADDR/ORIENT must FLOAT - no footprint, or DNP. Standalone GPIO mode: two resistors set the request. No I2C, no MCU, no firmware, no switching regulator.

an OPEN R23 requests 28 V -> requests 1.5 A

level references VDD - see README, test 9. Overvoltage interlock - trips at 10.0 V, survives 28 V

OVP / UVP / OTP. R28 is Q21's base resistor. If the LED never EN_N + FLGIN to GND = enabled

FAULT/OUT2 goes HIGH when no source PDO covers the request, or on

28 V fault. It clamps VGS to -10 V and parks U21's cathode D22 is not optional: without it Q22 sees VGS = -25.5 V at a

at VBUS - 10 V, which is above the 7.0 V REF tap.

Vtrip = 2.495 x (R30 + R31) / R31 = 10.00 V Sense VBUS, not the load: opening Q20 does not remove
the trip condition, so no hysteresis is needed. 9.45 V, so 310 mV of margin. worst case 9.76 - 10.25 V. The 9 V PDO high corner is

BOM, footprints and test matrix in ../BOM.md and ../README.md +3V3

Lower block: hardware overvoltage interlock, trips at 10.0 V.
HUSB238A-BB001, GPIO mode. No I2C, no MCU, no firmware.
Arduino_NMR_5.4 - NMR spectrometer
Sheet: /
File: usbc-power.kicad_sch
Title: USB-C PD to fixed 9 V input

Size: A3 | Rev: A | F Date: 2026-09-18
KiCad E.D.A. 10.0.6 | Id: 1/1

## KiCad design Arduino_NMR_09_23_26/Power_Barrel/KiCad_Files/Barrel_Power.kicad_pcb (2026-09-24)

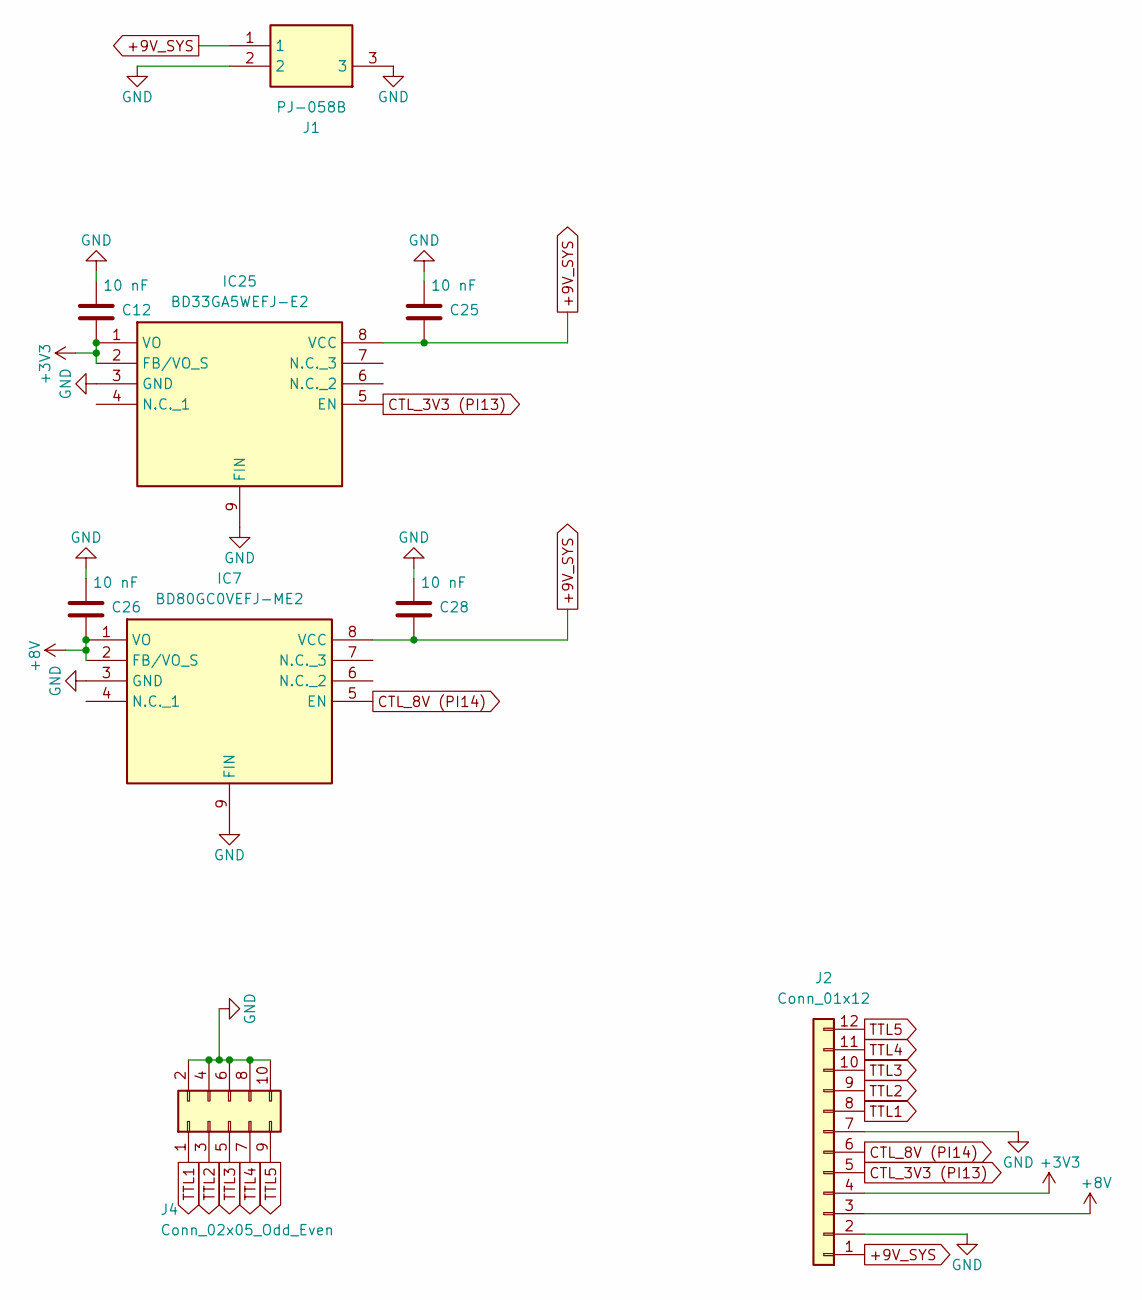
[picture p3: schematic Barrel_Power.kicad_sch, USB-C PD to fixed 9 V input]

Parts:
C12, C25, C26, C28: 10 nF; C_0805_2012Metric_Pad1.18x1.45mm_HandSolder
IC7: BD80GC0VEFJ-ME2; SOIC127P600X100-9N; Mouser Part Number 755-BD80GC0MEFJ-ME2
IC25: BD33GA5WEFJ-E2; SOIC127P600X100-9N; Mouser Part Number 755-BD80GC0MEFJ-ME2
J1: PJ-058B; PJ058B; Mouser Part Number 490-PJ-058B
J2: Conn_01x12; PinHeader_1x12_P2.54mm_Vertical
J4: Conn_02x05_Odd_Even; PinHeader_2x05_P2.54mm_Horizontal

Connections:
+3V3: C12.1, IC25.1 (VO), IC25.2 (FB/VO_S), J2.4
+8V: C26.1, IC7.1 (VO), IC7.2 (FB/VO_S), J2.3
+9V_SYS: C25.1, C28.1, IC7.8 (VCC), IC25.8 (VCC), J1.1, J2.1
CTL_3V3 (PI13): IC25.5 (EN), J2.5
CTL_8V (PI14): IC7.5 (EN), J2.6
GND: C12.2, C25.2, C26.2, C28.2, IC7.3 (GND), IC7.9 (FIN), IC25.3 (GND), IC25.9 (FIN), J1.2, J1.3, J2.2, J2.7, J4.2, J4.4, J4.6, J4.8, J4.10
TTL1: J2.8, J4.1
TTL2: J2.9, J4.3
TTL3: J2.10, J4.5
TTL4: J2.11, J4.7
TTL5: J2.12, J4.9

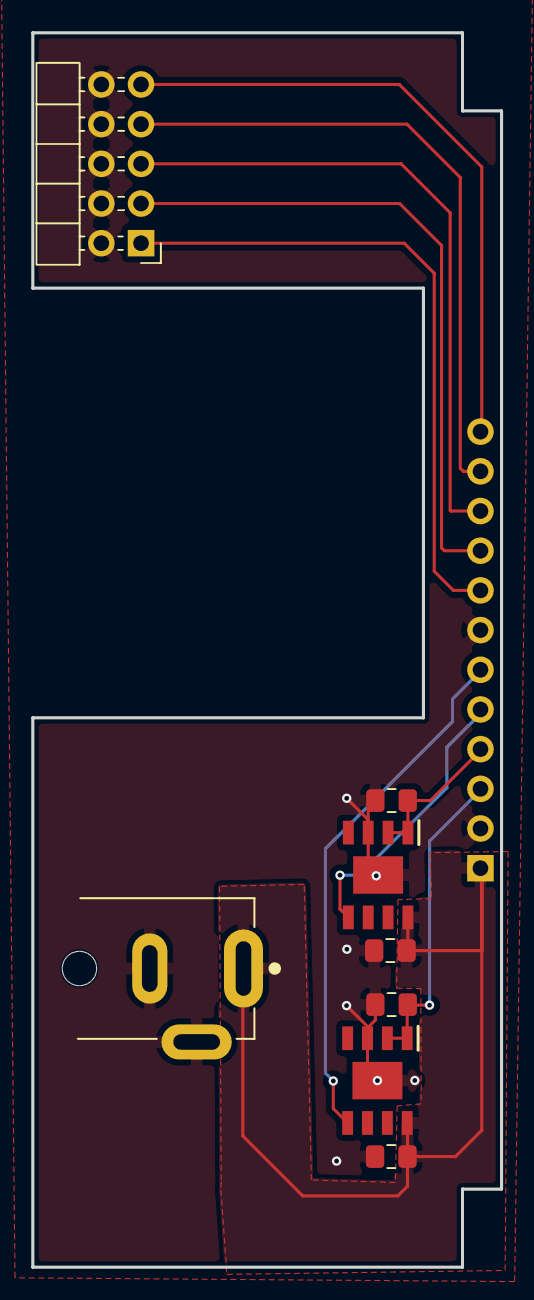
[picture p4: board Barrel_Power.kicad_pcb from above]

Board: 2 copper layers, 30.0 x 79.0 mm, 9 parts (0 on the bottom side), 11 nets.

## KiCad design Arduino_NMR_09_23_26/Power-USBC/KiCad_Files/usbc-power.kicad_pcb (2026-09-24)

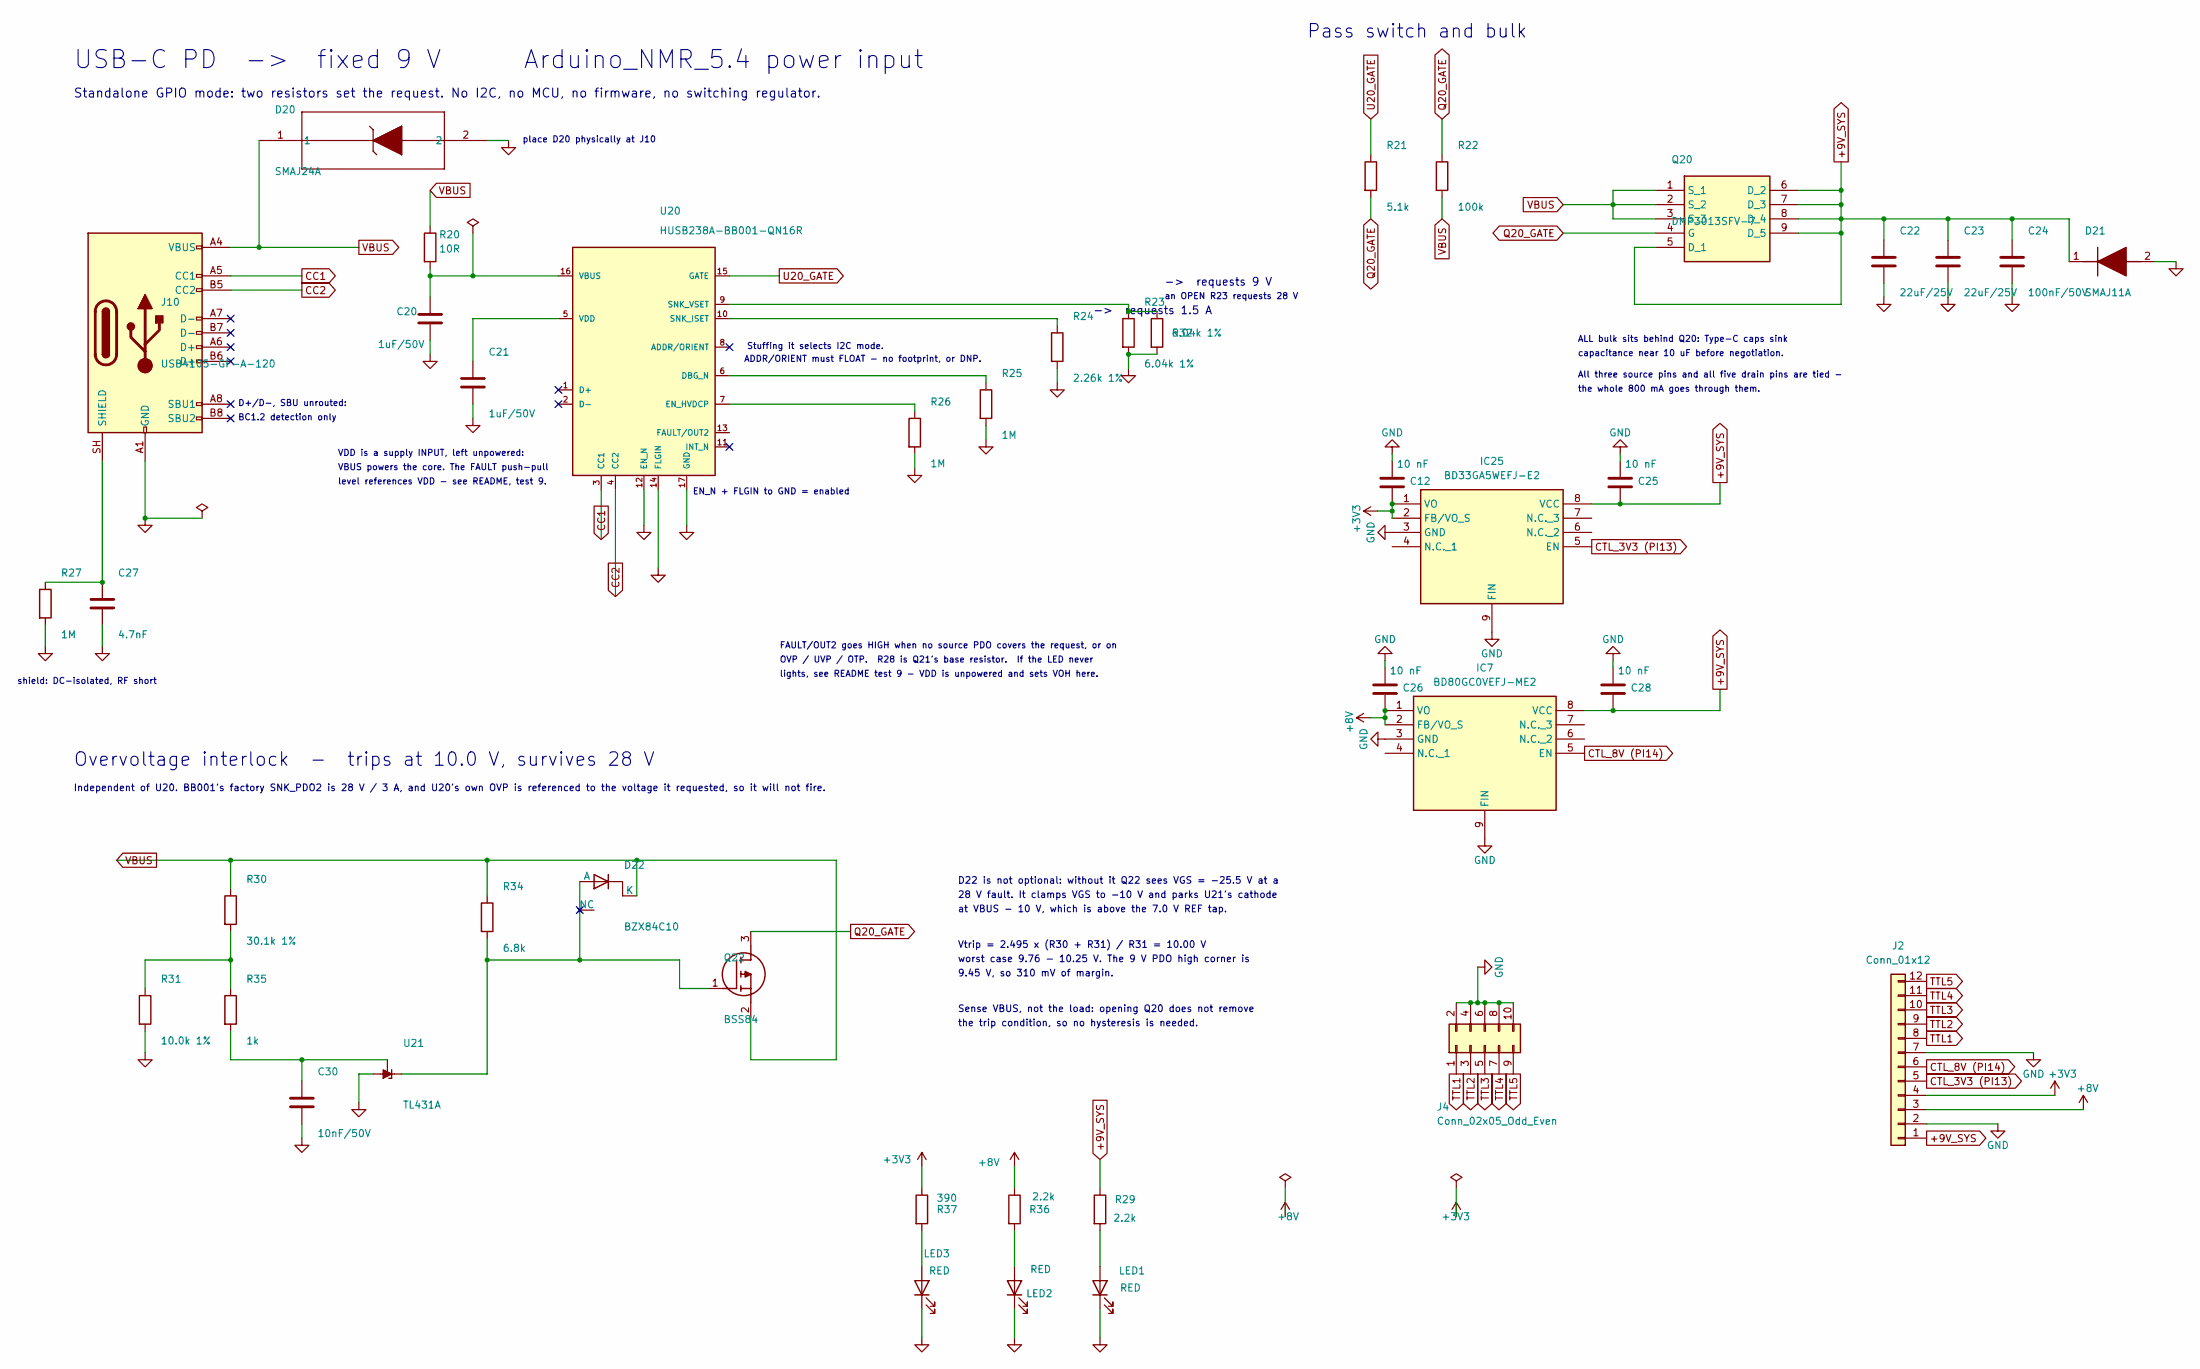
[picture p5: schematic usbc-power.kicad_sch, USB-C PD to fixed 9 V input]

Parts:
C12, C25, C26, C28: 10 nF; C_0805_2012Metric_Pad1.18x1.45mm_HandSolder
C20, C21: 1uF/50V; C_0603_1608Metric
C22, C23: 22uF/25V; C_1206_3216Metric
C24: 100nF/50V; C_0402_1005Metric
C27: 4.7nF; C_0402_1005Metric
C30: 10nF/50V; C_0402_1005Metric
D20: SMAJ24A; SMASeries_LTF; LCSC C132947
D21: SMAJ11A; DIOM5127X229N
D22: BZX84C10; P200_SOT-23; LCSC C118575
IC7: BD80GC0VEFJ-ME2; SOIC127P600X100-9N; Mouser Part Number 755-BD80GC0MEFJ-ME2
IC25: BD33GA5WEFJ-E2; SOIC127P600X100-9N; Mouser Part Number 755-BD80GC0MEFJ-ME2
J2: Conn_01x12; PinHeader_1x12_P2.54mm_Vertical
J4: Conn_02x05_Odd_Even; PinHeader_2x05_P2.54mm_Horizontal
J10: USB4105-GF-A-120; USB_C_Receptacle_GCT_USB4105-xx-A_16P_TopMnt_Horizontal
LED1, LED2, LED3: RED; LED_0805_2012Metric; LCSC C2295
Q20: DMP3013SFV-7; DMP3036SFV7; LCSC C264098
Q22: BSS84; SOT95P240X120-3N; LCSC C114481
R20: 10R; R_0402_1005Metric
R21: 5.1k; R_0402_1005Metric
R22: 100k; R_0402_1005Metric
R23, R32: 6.04k 1%; R_0402_1005Metric
R24: 2.26k 1%; R_0402_1005Metric
R25, R26, R27: 1M; R_0402_1005Metric
R29, R36: 2.2k; R_0402_1005Metric
R30: 30.1k 1%; R_0402_1005Metric
R31: 10.0k 1%; R_0402_1005Metric
R34: 6.8k; R_0402_1005Metric
R35: 1k; R_0402_1005Metric
R37: 390; R_0402_1005Metric
U20: HUSB238A-BB001-QN16R; QFN-16-1EP_3x3mm_P0.5mm_EP1.7x1.7mm_ThermalVias; LCSC C24833806
U21: TL431A; SOT-23

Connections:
+3V3: C12.1, IC25.1 (VO), IC25.2 (FB/VO_S), J2.4, R37.1
+3V3_USB: C21.1, U20.5 (VDD)
+8V: C26.1, IC7.1 (VO), IC7.2 (FB/VO_S), J2.3, R36.1
+9V_SYS: C22.1, C23.1, C24.1, C25.1, C28.1, D21.1 (K), IC7.8 (VCC), IC25.8 (VCC), J2.1, Q20.5 (D_1), Q20.6 (D_2), Q20.7 (D_3), Q20.8 (D_4), Q20.9 (D_5), R29.1
CC1: J10.A5 (CC1), U20.3 (CC1)
CC2: J10.B5 (CC2), U20.4 (CC2)
CTL_3V3 (PI13): IC25.5 (EN), J2.5
CTL_8V (PI14): IC7.5 (EN), J2.6
GND: C12.2, C20.2, C21.2, C22.2, C23.2, C24.2, C25.2, C26.2, C27.2, C28.2, C30.2, D20.2, D21.2 (A), IC7.3 (GND), IC7.9 (FIN), IC25.3 (GND), IC25.9 (FIN), J2.2, J2.7, J4.2, J4.4, J4.6, J4.8, J4.10, J10.A1 (GND), J10.A12 (GND), J10.B1 (GND), J10.B12 (GND), LED1.1 (K), LED2.1 (K), LED3.1 (K), R23.2, R24.2, R25.2, R26.2, R27.2, R31.2, R32.2, U20.12 (EN_N), U20.14 (FLGIN), U20.17 (GND), U21.3 (A)
unnamed: D22.1 (A), Q22.1 (G), R34.2, U21.1 (K)
unnamed: C27.1, J10.SH (SHIELD), R27.1
unnamed: LED1.2 (A), R29.2
unnamed: LED2.2 (A), R36.2
unnamed: LED3.2 (A), R37.2
unnamed: R30.2, R31.1, R35.1
unnamed: R25.1, U20.6 (DBG_N)
unnamed: R26.1, U20.7 (EN_HVDCP)
unnamed: R24.1, U20.10 (SNK_ISET)
unnamed: R23.1, R32.1, U20.9 (SNK_VSET)
unnamed: C20.1, R20.2, U20.16 (VBUS)
unnamed: C30.1, R35.2, U21.2 (REF)
Q20_GATE: Q20.4 (G), Q22.3 (D), R21.2, R22.1
TTL1: J2.8, J4.1
TTL2: J2.9, J4.3
TTL3: J2.10, J4.5
TTL4: J2.11, J4.7
TTL5: J2.12, J4.9
U20_GATE: R21.1, U20.15 (GATE)
VBUS: D20.1, D22.3 (K), J10.A4 (VBUS), J10.A9 (VBUS), J10.B4 (VBUS), J10.B9 (VBUS), Q20.1 (S_1), Q20.2 (S_2), Q20.3 (S_3), Q22.2 (S), R20.1, R22.2, R30.1, R34.1

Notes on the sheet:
VDD is a supply INPUT, left unpowered:
at VBUS - 10 V, which is above the 7.0 V REF tap.
lights, see README test 9 - VDD is unpowered and sets VOH here.
FAULT/OUT2 goes HIGH when no source PDO covers the request, or on
worst case 9.76 - 10.25 V. The 9 V PDO high corner is
an OPEN R23 requests 28 V
-> requests 9 V
capacitance near 10 uF before negotiation.
BC1.2 detection only
Pass switch and bulk
ALL bulk sits behind Q20: Type-C caps sink
place D20 physically at J10
D22 is not optional: without it Q22 sees VGS = -25.5 V at a
OVP / UVP / OTP. R28 is Q21's base resistor. If the LED never
-> requests 1.5 A
Independent of U20. BB001's factory SNK_PDO2 is 28 V / 3 A, and U20's own OVP is referenced to the voltage it requested, so it will not fire.
VBUS powers the core. The FAULT push-pull
Standalone GPIO mode: two resistors set the request. No I2C, no MCU, no firmware, no switching regulator.
Overvoltage interlock - trips at 10.0 V, survives 28 V
9.45 V, so 310 mV of margin.
shield: DC-isolated, RF short
the trip condition, so no hysteresis is needed.
level references VDD - see README, test 9.
Sense VBUS, not the load: opening Q20 does not remove
28 V fault. It clamps VGS to -10 V and parks U21's cathode
USB-C PD -> fixed 9 V Arduino_NMR_5.4 power input
the whole 800 mA goes through them.
Vtrip = 2.495 x (R30 + R31) / R31 = 10.00 V
EN_N + FLGIN to GND = enabled
Stuffing it selects I2C mode.
All three source pins and all five drain pins are tied -
ADDR/ORIENT must FLOAT - no footprint, or DNP.
D+/D-, SBU unrouted:

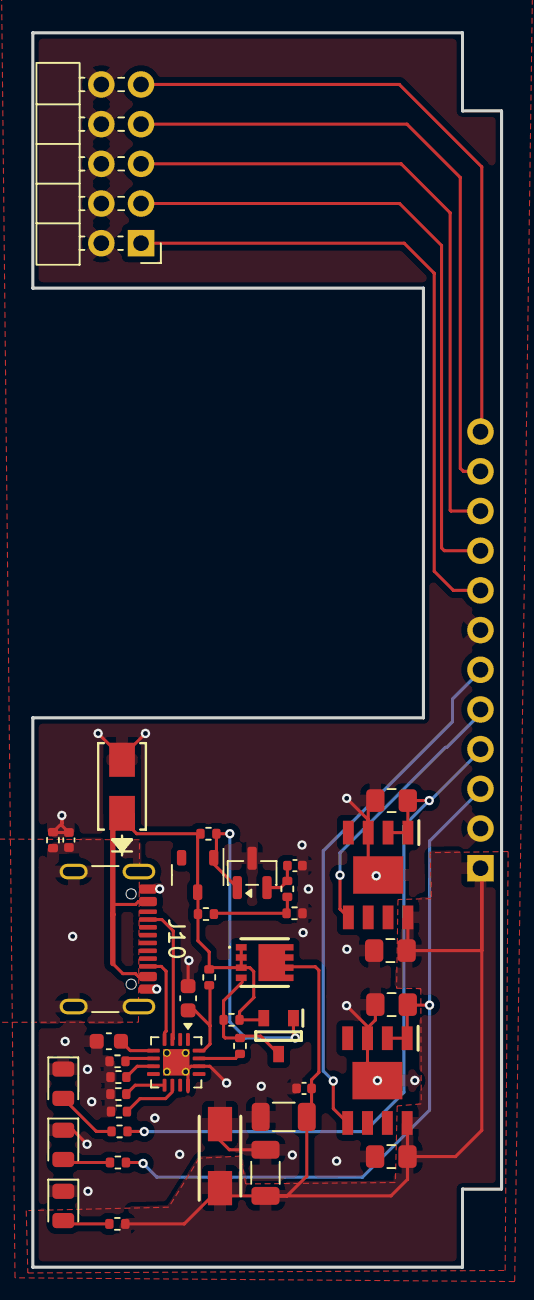
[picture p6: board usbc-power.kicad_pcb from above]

Board: 2 copper layers, 30.0 x 79.0 mm, 41 parts (0 on the bottom side), 29 nets.

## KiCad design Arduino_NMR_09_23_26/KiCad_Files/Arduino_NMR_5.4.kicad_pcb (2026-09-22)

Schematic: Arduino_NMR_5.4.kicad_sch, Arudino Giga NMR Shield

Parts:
J16: RFShield_OnePiece; RF Shield_1
J17: RFShield_OnePiece; RF Shield_3
J32: RFShield_OnePiece; RF Shield_2

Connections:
GND: J16.1 (Shield_1), J17.1 (Shield_1), J32.1 (Shield_1); also elsewhere on the board

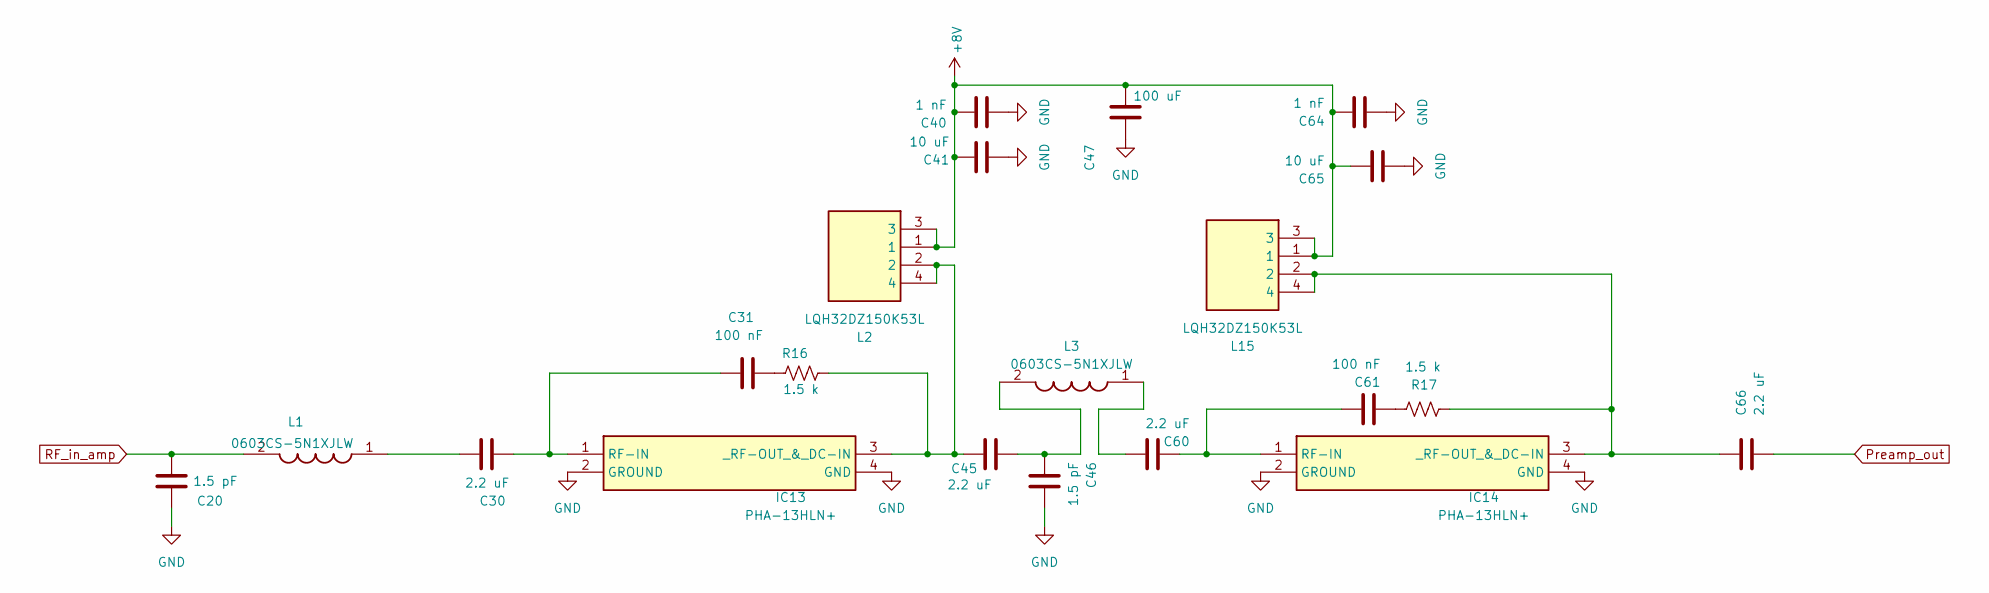
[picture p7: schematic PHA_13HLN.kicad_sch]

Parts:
C20, C46: 1.5 pF; C_0402_1005Metric; LCSC Part # 0402CG1R5C500NT
C30, C45, C60, C66: 2.2 uF; C_0603_1608Metric
C31, C61: 100 nF; C_0402_1005Metric; LCSC Part # CL05B104KO5NNNC
C40, C64: 1 nF; C_0402_1005Metric; LCSC Part # 0402B102K500NT
C41, C65: 10 uF; C_0805_2012Metric; LCSC Part # GRM21BR61H106KE43L
C47: 100 uF; C_Radial_D5.0mm_H5.0mm_P2.00mm
IC13, IC14: PHA-13HLN+; PHA13HLN; Mouser Part Number 139-PHA-13HLN
L1, L3: 0603CS-5N1XJLW; L_0603_1608Metric; Mouser Part Number 81-LQW18AS5N1J0ZD
L2, L15: LQH32DZ150K53L; L_1210_3225Metric_Pad1.42x2.65mm_HandSolder; Mouser Part Number 81-LQH32DZ150K53L
R16, R17: 1.5 k; R_0402_1005Metric_Pad0.72x0.64mm_HandSolder; LCSC Part # 0402WGF1501TCE

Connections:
+8V: C40.1, C41.1, C47.1, C64.1, C65.1, L2.1, L2.3, L15.1, L15.3; also elsewhere on the board
GND: C20.1, C40.2, C41.2, C46.1, C47.2, C64.2, C65.2, IC13.2 (GROUND), IC13.4 (GND), IC14.2 (GROUND), IC14.4 (GND); also elsewhere on the board
unnamed: C30.1, L1.1
unnamed: C31.2, R16.1
unnamed: C45.2, C46.2, L3.2
unnamed: C60.1, L3.1
unnamed: C61.2, R17.1
unnamed: C30.2, C31.1, IC13.1 (RF-IN)
unnamed: C45.1, IC13.3 (_RF-OUT_&_DC-IN), L2.2, L2.4, R16.2
unnamed: C60.2, C61.1, IC14.1 (RF-IN)
unnamed: C66.1, IC14.3 (_RF-OUT_&_DC-IN), L15.2, L15.4, R17.2
Preamp_out: C66.2; also elsewhere on the board
RF_in_amp: C20.2, L1.2; also elsewhere on the board

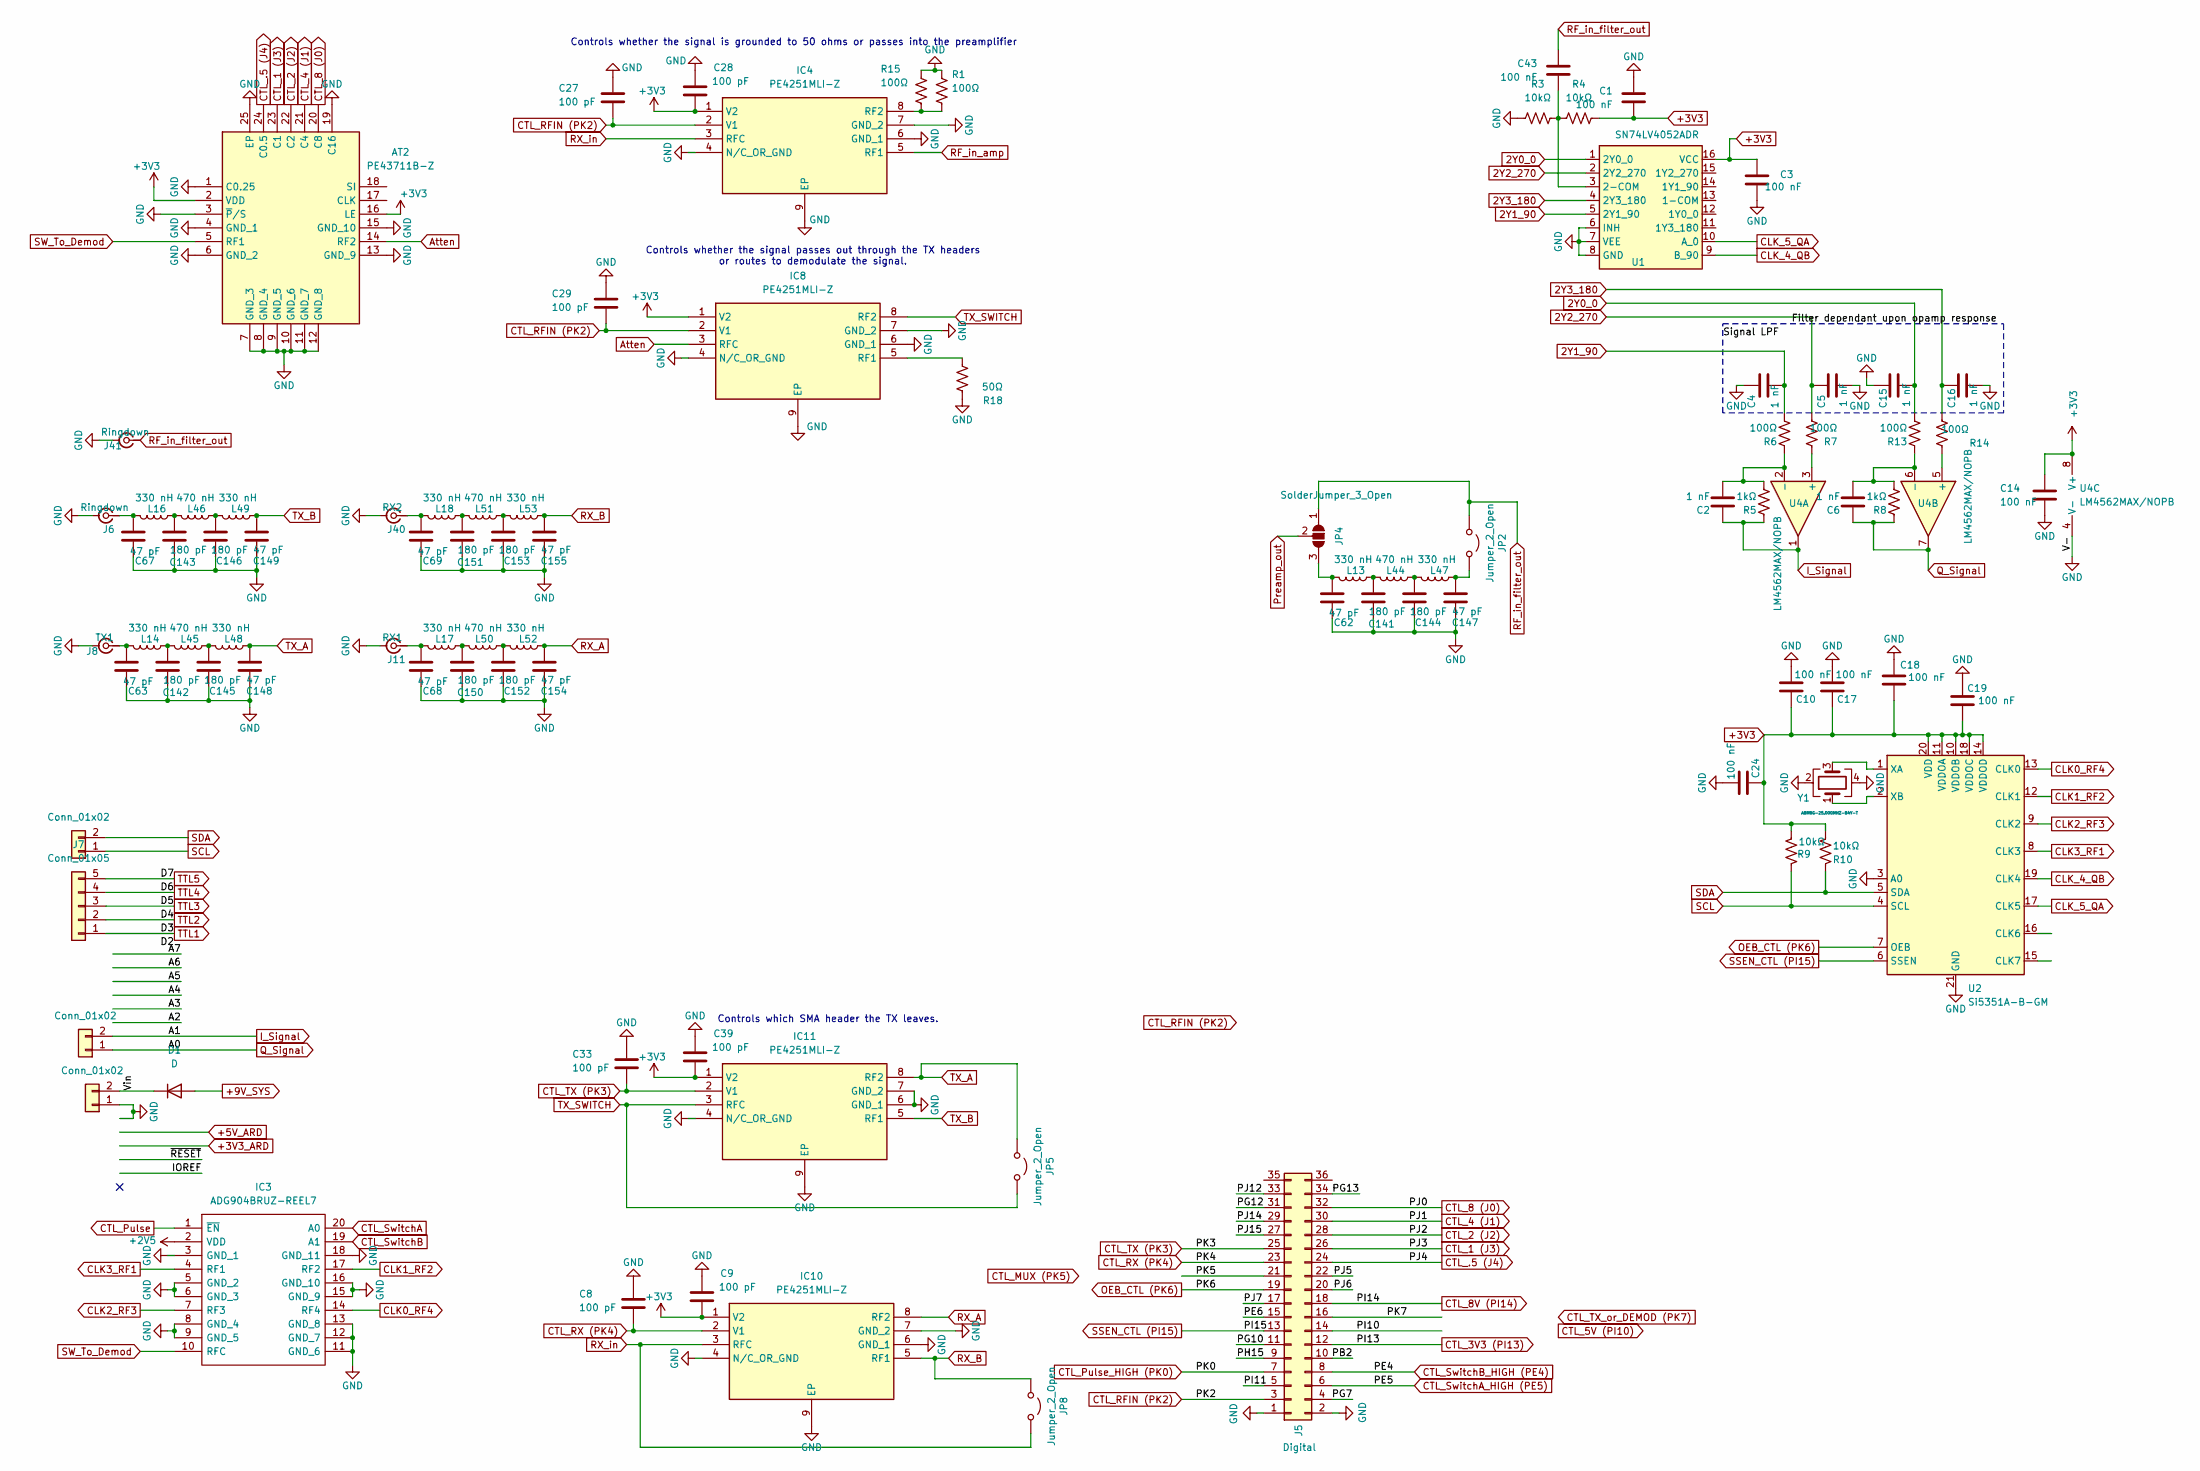
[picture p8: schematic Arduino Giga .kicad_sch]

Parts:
AT2: PE43711B-Z; Mouser Part Number 81-PE43711B-Z
C1, C3, C10, C14, C17, C18, C19, C24, C43: 100 nF; C_0805_2012Metric
C2, C4, C5, C6, C15, C16: 1 nF; C_0805_2012Metric
C8, C9, C27, C28, C29, C33, C39: 100 pF; C_0805_2012Metric
C62, C147: 47 pF; C_0805_2012Metric
C63, C67, C68, C69, C148, C149, C154, C155: 47 pF; C_0805_2012Metric_Pad1.18x1.45mm_HandSolder
C141, C144: 180 pF; C_0805_2012Metric
C142, C143, C145, C146, C150, C151, C152, C153: 180 pF; C_0805_2012Metric_Pad1.18x1.45mm_HandSolder
D1: D; D_SMA_Handsoldering
IC3: ADG904BRUZ-REEL7; ADG904BRUZ; Mouser Part Number 584-ADG904BRUZ-R7
IC4, IC8, IC10, IC11: PE4251MLI-Z; SOP65P490X106-9N; Mouser Part Number 81-PE4251MLI-Z
J4, J10, J12: Conn_01x02; PinHeader_1x02_P2.54mm_Vertical
J5: Digital; PinHeader_2x18_P2.54mm_Vertical
J6, J41: Ringdown; SMA_Amphenol_901-144_Vertical
J7: Conn_01x05; PinHeader_1x05_P2.54mm_Vertical
J8: TX1; SMA_Amphenol_901-144_Vertical
J11: RX1; SMA_Amphenol_901-144_Vertical
J40: RX2; SMA_Amphenol_901-144_Vertical
JP2, JP5, JP8: Jumper_2_Open; SolderJumper-2_P1.3mm_Open_Pad1.0x1.5mm
JP4: SolderJumper_3_Open; SolderJumper-3_P1.3mm_Open_Pad1.0x1.5mm
L13, L47: 330 nH; L_0805_2012Metric_Pad1.15x1.40mm_HandSolder
L14, L16, L17, L18, L48, L49, L52, L53: 330 nH; L_0805_2012Metric_Pad1.05x1.20mm_HandSolder
L44: 470 nH; L_0805_2012Metric_Pad1.15x1.40mm_HandSolder
L45, L46, L50, L51: 470 nH; L_0805_2012Metric_Pad1.05x1.20mm_HandSolder
R1, R6, R7, R13, R14, R15: 100Ω; R_0805_2012Metric_Pad1.20x1.40mm_HandSolder
R3, R4, R9, R10: 10kΩ; R_0805_2012Metric_Pad1.20x1.40mm_HandSolder
R5, R8: 1kΩ; R_0805_2012Metric_Pad1.20x1.40mm_HandSolder; LCSC Part # 0805W8F1001T5E
R18: 50Ω; R_0805_2012Metric_Pad1.20x1.40mm_HandSolder
U1: SN74LV4052ADR; SOIC-16_3.9x9.9mm_P1.27mm
U2: Si5351A-B-GM; QFN-20-1EP_4x4mm_P0.5mm_EP2.7x2.7mm
U4: LM4562MAX/NOPB; SOIC-8-1EP_3.9x4.9mm_P1.27mm_EP2.29x3mm_nobottomgnd
Y1: ABM8G-25.000MHZ-B4Y-T; Crystal_SMD_SeikoEpson_FA238-4Pin_3.2x2.5mm_HandSoldering

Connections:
2Y0_0: C15.2, R13.2, U1.1 (2Y0_0)
2Y1_90: C4.2, R6.2, U1.5 (2Y1_90)
2Y2_270: C5.2, R7.2, U1.2 (2Y2_270)
2Y3_180: C16.2, R14.2, U1.4 (2Y3_180)
+2V5: IC3.2 (VDD); also elsewhere on the board
+3V3: AT2.2 (VDD), AT2.16 (LE), C1.2, C3.1, C9.2, C10.2, C14.1, C17.2, C18.2, C19.2, C24.2, C28.2, C39.2, IC4.1 (V2), IC8.1 (V2), IC10.1 (V2), IC11.1 (V2), R4.2, R9.2, R10.2, U1.16 (VCC), U2.10 (VDDOB), U2.11 (VDDOA), U2.14 (VDDOD), U2.18 (VDDOC), U2.20 (VDD), U4.8 (V+); also elsewhere on the board
+9V_SYS: D1.2 (A); also elsewhere on the board
/Arduino Giga Sheet/PB2: J5.10
/Arduino Giga Sheet/PE6: J5.15
/Arduino Giga Sheet/PG7: J5.4
/Arduino Giga Sheet/PG10: J5.11
/Arduino Giga Sheet/PG12: J5.31
/Arduino Giga Sheet/PG13: J5.34
/Arduino Giga Sheet/PH15: J5.9
/Arduino Giga Sheet/PI10: J5.14
/Arduino Giga Sheet/PI11: J5.5
/Arduino Giga Sheet/PJ5: J5.22
/Arduino Giga Sheet/PJ6: J5.20
/Arduino Giga Sheet/PJ7: J5.17
/Arduino Giga Sheet/PJ12: J5.33
/Arduino Giga Sheet/PJ14: J5.29
/Arduino Giga Sheet/PJ15: J5.27
/Arduino Giga Sheet/PK5: J5.21
/Arduino Giga Sheet/PK7: J5.16
/Arduino Giga Sheet/Vin: D1.1 (K), J10.2
Atten: AT2.14 (RF2), IC8.3 (RFC)
CLK0_RF4: IC3.14 (RF4), U2.13 (CLK0)
CLK1_RF2: IC3.17 (RF2), U2.12 (CLK1)
CLK2_RF3: IC3.7 (RF3), U2.9 (CLK2)
CLK3_RF1: IC3.4 (RF1), U2.8 (CLK3)
CLK_4_QB: U1.9 (B_90), U2.19 (CLK4)
CLK_5_QA: U1.10 (A_0), U2.17 (CLK5)
CTL_1 (J3): AT2.23 (C1), J5.26
CTL_2 (J2): AT2.22 (C2), J5.28
CTL_3V3 (PI13): J5.12; also elsewhere on the board
CTL_4 (J1): AT2.21 (C4), J5.30
CTL_8 (J0): AT2.20 (C8), J5.32
CTL_8V (PI14): J5.18; also elsewhere on the board
CTL_.5 (J4): AT2.24 (C0.5), J5.24
CTL_Pulse: IC3.1 (~EN); also elsewhere on the board
CTL_Pulse_HIGH (PK0): J5.7; also elsewhere on the board
CTL_RFIN (PK2): C27.2, C29.2, IC4.2 (V1), IC8.2 (V1), J5.3
CTL_RX (PK4): C8.2, IC10.2 (V1), J5.23
CTL_SwitchA: IC3.20 (A0); also elsewhere on the board
CTL_SwitchA_HIGH (PE5): J5.6; also elsewhere on the board
CTL_SwitchB: IC3.19 (A1); also elsewhere on the board
CTL_SwitchB_HIGH (PE4): J5.8; also elsewhere on the board
CTL_TX (PK3): C33.2, IC11.2 (V1), J5.25
GND: AT2.1 (C0.25), AT2.3 (~P/S), AT2.4 (GND_1), AT2.6 (GND_2), AT2.7 (GND_3), AT2.8 (GND_4), AT2.9 (GND_5), AT2.10 (GND_6), AT2.11 (GND_7), AT2.12 (GND_8), AT2.13 (GND_9), AT2.15 (GND_10), AT2.19 (C16), AT2.25 (EP), C1.1, C3.2, C4.1, C5.1, C8.1, C9.1, C10.1, C14.2, C15.1, C16.1, C17.1, C18.1, C19.1, C24.1, C27.1, C28.1, C29.1, C33.1, C39.1, C62.1, C63.1, C67.1, C68.1, C69.1, C141.1, C142.1, C143.1, C144.1, C145.1, C146.1, C147.1, C148.1, C149.1, C150.1, C151.1, C152.1, C153.1, C154.1, C155.1, IC3.3 (GND_1), IC3.5 (GND_2), IC3.6 (GND_3), IC3.8 (GND_4), IC3.9 (GND_5), IC3.11 (GND_6), IC3.12 (GND_7), IC3.13 (GND_8), IC3.15 (GND_9), IC3.16 (GND_10), IC3.18 (GND_11), IC4.4 (N/C_OR_GND), IC4.6 (GND_1), IC4.7 (GND_2), IC4.9 (EP), IC8.4 (N/C_OR_GND), IC8.6 (GND_1), IC8.7 (GND_2), IC8.9 (EP), IC10.4 (N/C_OR_GND), IC10.6 (GND_1), IC10.7 (GND_2), IC10.9 (EP), IC11.4 (N/C_OR_GND), IC11.6 (GND_1), IC11.7 (GND_2), IC11.9 (EP), J5.1, J5.2, J6.2 (Ext), J8.2 (Ext), J10.1, J11.2 (Ext), J40.2 (Ext), J41.2 (Ext), R1.2, R3.1, R15.2, R18.2, U1.6 (INH), U1.7 (VEE), U1.8 (GND), U2.3 (A0), U2.21 (GND), U4.4 (V-), Y1.2, Y1.4; also elsewhere on the board
I_Signal: C2.1, J12.2, R5.1, U4.1
unnamed: C141.2, L13.1, L44.2
unnamed: C142.2, L14.1, L45.2
unnamed: C143.2, L16.1, L46.2
unnamed: C144.2, L44.1, L47.2
unnamed: C145.2, L45.1, L48.2
unnamed: C146.2, L46.1, L49.2
unnamed: C150.2, L17.1, L50.2
unnamed: C151.2, L18.1, L51.2
unnamed: C152.2, L50.1, L52.2
unnamed: C153.2, L51.1, L53.2
unnamed: IC4.8 (RF2), R1.1, R15.1
unnamed: IC8.5 (RF1), R18.1
unnamed: C67.2, J6.1 (In), L16.2
unnamed: C63.2, J8.1 (In), L14.2
unnamed: C68.2, J11.1 (In), L17.2
unnamed: C69.2, J40.1 (In), L18.2
unnamed: C147.2, JP2.1 (A), L47.1
unnamed: C62.2, JP4.3 (B), L13.2
unnamed: C43.2, R3.2, R4.1, U1.3 (2-COM)
unnamed: U2.1 (XA), Y1.3
unnamed: U2.2 (XB), Y1.1
unnamed: R7.1, U4.3 (+)
unnamed: C2.2, R5.2, R6.1, U4.2 (-)
unnamed: R14.1, U4.5 (+)
unnamed: C6.2, R8.2, R13.1, U4.6 (-)
OEB_CTL (PK6): J5.19, U2.7 (OEB)
Preamp_out: JP4.2 (C); also elsewhere on the board
Q_Signal: C6.1, J12.1, R8.1, U4.7
RF_in_amp: IC4.5 (RF1); also elsewhere on the board
RF_in_filter_out: C43.1, J41.1 (In), JP2.2 (B), JP4.1 (A)
RX_A: C154.2, IC10.8 (RF2), L52.1
RX_B: C155.2, IC10.5 (RF1), JP8.2 (B), L53.1
RX_in: IC4.3 (RFC), IC10.3 (RFC), JP8.1 (A)
SCL: J4.1, R9.1, U2.4 (SCL)
SDA: J4.2, R10.1, U2.5 (SDA)
SSEN_CTL (PI15): J5.13, U2.6 (SSEN)
SW_To_Demod: AT2.5 (RF1), IC3.10 (RFC)
TTL1: J7.1; also elsewhere on the board
TTL2: J7.2; also elsewhere on the board
TTL3: J7.3; also elsewhere on the board
TTL4: J7.4; also elsewhere on the board
TTL5: J7.5; also elsewhere on the board
TX_A: C148.2, IC11.8 (RF2), JP5.2 (B), L48.1
TX_B: C149.2, IC11.5 (RF1), L49.1
TX_SWITCH: IC8.8 (RF2), IC11.3 (RFC), JP5.1 (A)

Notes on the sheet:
Controls whether the signal is grounded to 50 ohms or passes into the preamplifier
Controls whether the signal passes out through the TX headers or routes to demodulate the signal.
Controls which SMA header the TX leaves.

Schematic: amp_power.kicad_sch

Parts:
C34: 100 nF; C_0805_2012Metric
C48: 1 uF; C_0805_2012Metric
IC1, IC2, IC12: SN74LV1T04DBVR; SOT95P280X145-5N; Mouser Part Number 595-SN74LV1T04DBVR
IC5: TLV74125PDBVR; SOT95P280X145-5N; Mouser Part Number 595-TLV74125PDBVR
J2: Conn_01x12; PinHeader_1x12_P2.54mm_Vertical

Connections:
+2V5: C48.1, IC1.5 (VCC), IC2.5 (VCC), IC5.5 (OUT), IC12.5 (VCC); also elsewhere on the board
+3V3: C34.2, IC5.1 (IN), IC5.3 (EN), J2.4; also elsewhere on the board
+8V: J2.3; also elsewhere on the board
+9V_SYS: J2.1; also elsewhere on the board
CTL_3V3 (PI13): J2.5; also elsewhere on the board
CTL_8V (PI14): J2.6; also elsewhere on the board
CTL_Pulse: IC12.4 (Y); also elsewhere on the board
CTL_Pulse_HIGH (PK0): IC12.2 (A); also elsewhere on the board
CTL_SwitchA: IC2.4 (Y); also elsewhere on the board
CTL_SwitchA_HIGH (PE5): IC2.2 (A); also elsewhere on the board
CTL_SwitchB: IC1.4 (Y); also elsewhere on the board
CTL_SwitchB_HIGH (PE4): IC1.2 (A); also elsewhere on the board
GND: C34.1, C48.2, IC1.3 (GND), IC2.3 (GND), IC5.2 (GND), IC12.3 (GND); also elsewhere on the board
TTL1: J2.8; also elsewhere on the board
TTL2: J2.9; also elsewhere on the board
TTL3: J2.10; also elsewhere on the board
TTL4: J2.11; also elsewhere on the board
TTL5: J2.12; also elsewhere on the board

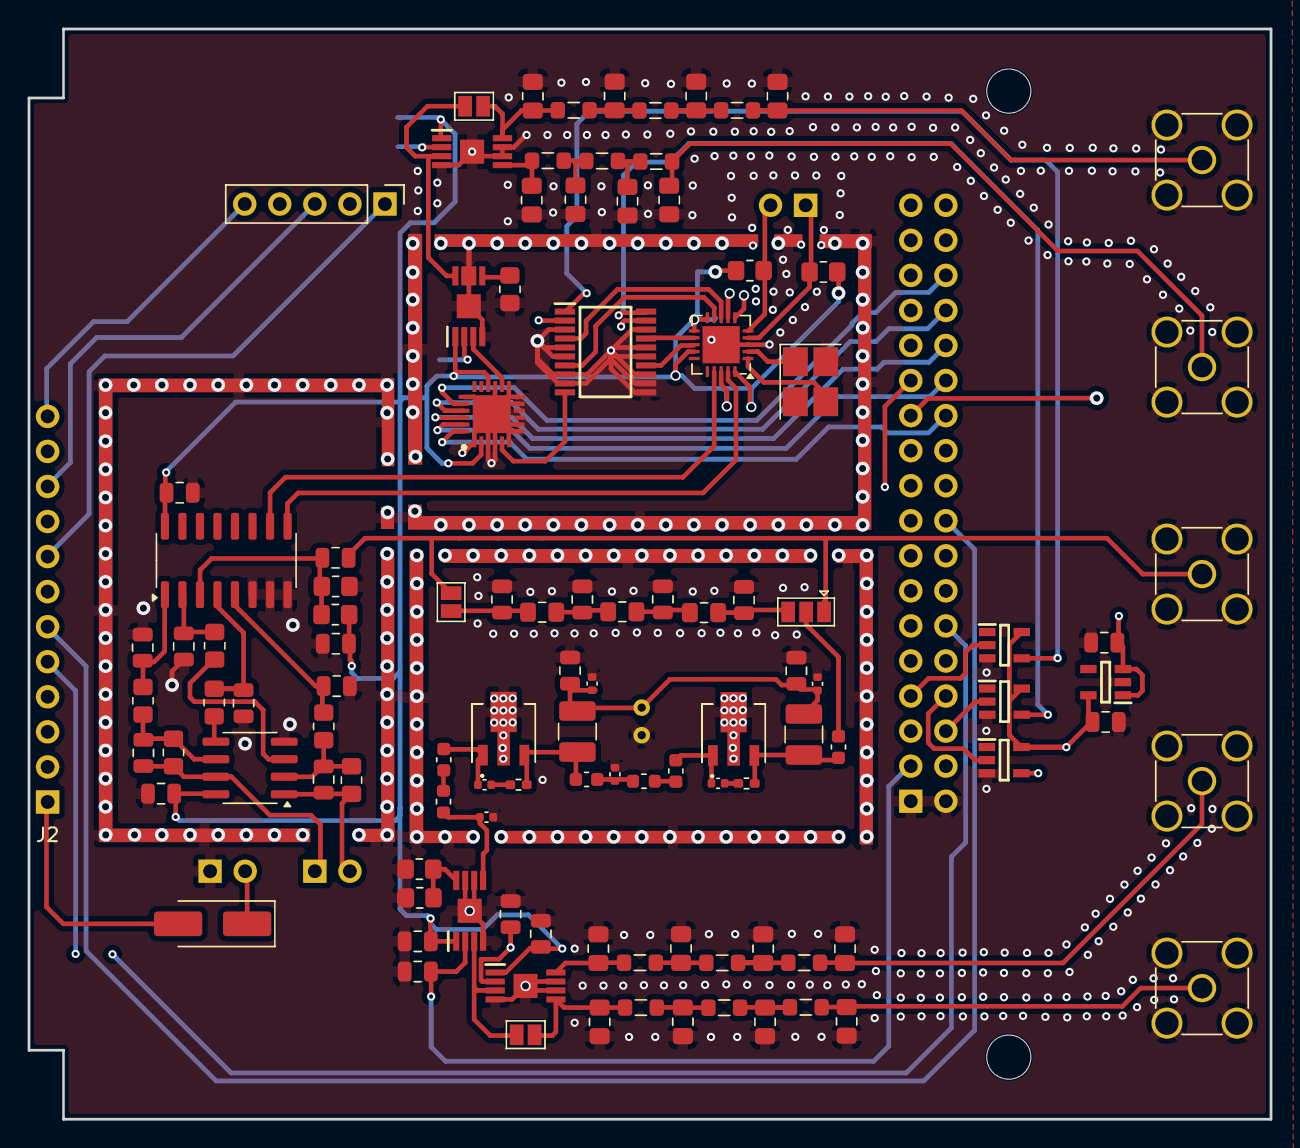
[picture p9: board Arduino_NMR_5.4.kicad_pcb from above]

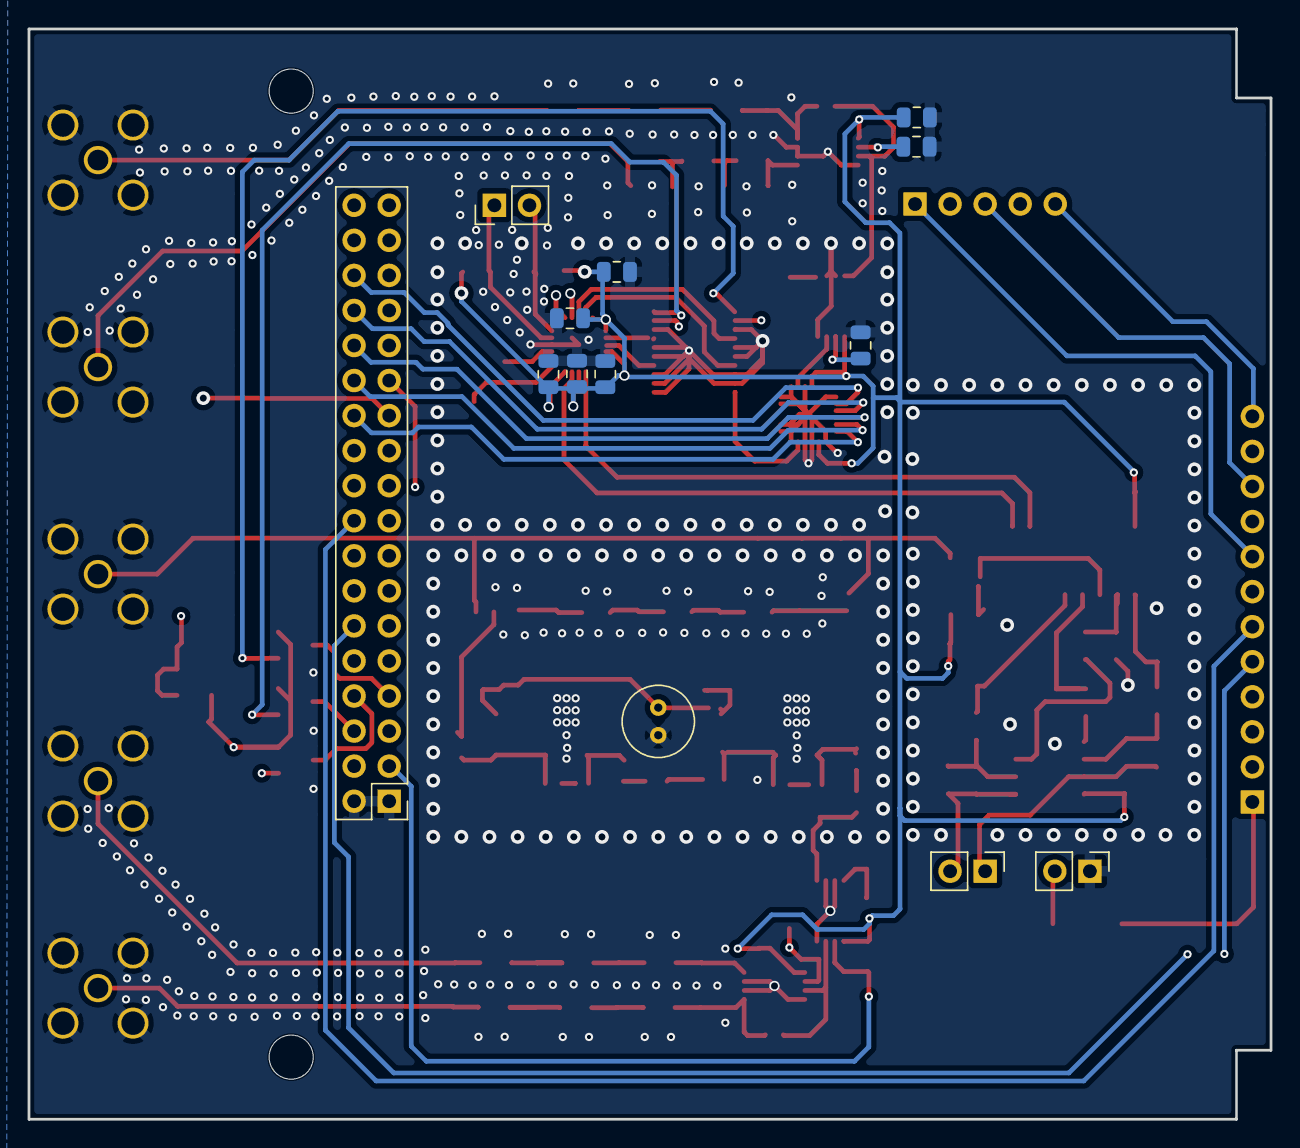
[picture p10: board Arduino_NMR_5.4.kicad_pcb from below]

Board: 4 copper layers, 90.0 x 79.0 mm, 126 parts (13 on the bottom side), 88 nets.

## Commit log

2026-05-31 Add files via upload
    Committed is my most up to date PCB for the Arduino NMR project.
    [Active_switch.kicad_sch, Amplifier 2.kicad_sch, Arduino Giga .kicad_sch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]
2026-06-01 Update README with June 2026 details and to-do list
    Added June 2026 update with to-do list and detailed explanations of the Arduino NMR system components and configurations.
2026-08-31 Initial commit: Arduino NMR 5.2 KiCad hardware design
    Schematics, PCB, custom footprint/symbol libraries, and fabrication
    outputs for the Arduino NMR 5.2 board.
    [Active_switch.kicad_sch, Amplifier 2.kicad_sch, Arduino Giga .kicad_sch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]
2026-09-22 Arduino NMR 5.4: self-contained libraries, split BOMs, production release
    Consolidate every footprint the design uses into Arduino_NMR.pretty so a
    fresh clone resolves without the author's personal library table. Recover
    L_0805_2012Metric_Pad1.15x1.40mm_HandSolder, dropped from KiCad 10's stock
    library, from the board itself. Repoint 261 references and drop the dead
    'Library' fp-lib-table entry.
    Add tools/split_bom.py, which splits the board into JLCPCB assembly, back-side
    hand solder, front-side hand solder and off-board parts, with matching
    placement files. Chip packages are normalised to the short form (0402, 0805)
    because the full KiCad name makes JLCPCB's matcher offer 01005 parts.
    Ad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
    [1_jlcpcb_assembly.csv, 2_handsolder_back.csv, 2_handsolder_back_placement.csv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]
2026-09-24 Reorganise repo: current board in Arduino_NMR_09_23_26, June board in Past Boards
    - KiCad project moved to Arduino_NMR_09_23_26/KiCad_Files
    - bom/ consolidated into Arduino_NMR_09_23_26/BOM_09_23_26.csv
    - JLCPCB upload files moved to production/; raw toolkit output renamed donotuse_*
    - archive/ and tools/ removed
    [1_jlcpcb_assembly.csv, 2_handsolder_back.csv, 2_handsolder_back_placement.csv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]
2026-09-24 Add Power-USBC and Power_Barrel boards; move README, LICENSE, CHANGELOG, BOM to root
    - Power-USBC: as sent to production 2026-09-22, with combined BOM, fresh
    schematic PDF, and JLCPCB files in production/
    - Power_Barrel: barrel-jack variant, not yet ordered
    - Both boards self-contained: stock pin header and 0805 footprints, the
    PJ-058B barrel jack and the ROHM LDO symbol moved into project libraries
    [1_jlcpcb_assembly.csv, BOM_09_23_26.csv, BOM_Barrel_09_23_26.csv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]
2026-09-24 README: add pulse code and housing CAD/CAM to the to-do list
2026-10-24 Create CITATION.cff for Arduino NMR project
    Added citation metadata for Arduino NMR project including authors, version, license, and abstract.
